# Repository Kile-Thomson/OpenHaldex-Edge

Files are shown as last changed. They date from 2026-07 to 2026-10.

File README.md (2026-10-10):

<p align="center">
  <a href="https://forbes-automotive.com/?utm_source=github&utm_medium=readme&utm_campaign=openhaldex" target="_blank">
    <picture>
      <source media="(prefers-color-scheme: dark)" srcset="/Images/FA-logo-white.png">
      <source media="(prefers-color-scheme: light)" srcset="/Images/FA-logo.png">
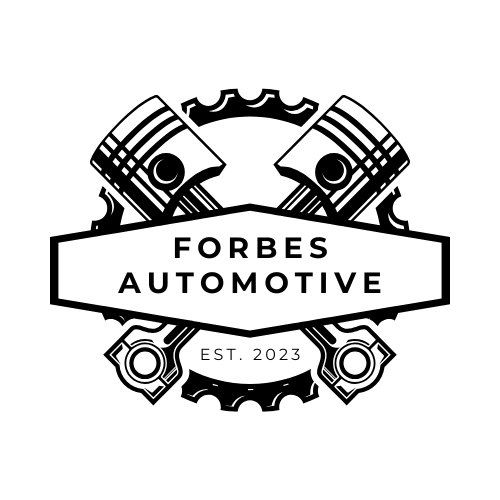
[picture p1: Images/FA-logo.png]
Forbes Automotive
      
    </picture>
  </a>
</p>

# OpenHaldex Edge

> [!IMPORTANT]
> **OpenHaldex Edge is a fork of [Forbes Automotive OpenHaldex-C6](https://github.com/Forbes-Automotive/OpenHaldex-C6).** Forbes did the hard work: the reverse engineering, the Gen2, Gen4 and Gen5 logic, the hardware and the open-source release. Edge starts from their V9.00.6 firmware and adds to it. Same hardware, same wiring, same modes.
>
> Edge uses the **same MIT licence** as upstream, with nothing added to it. There are no plans to restrict it, now or later. Edge's own code is contributed under the same terms. See [Licensing](#licensing).
>
> For assembled modules, official firmware and support, go to [forbes-automotive.com](https://forbes-automotive.com/). Edge is a personal project, not affiliated with or endorsed by Forbes Automotive. Credit for the platform is in [Acknowledgements](#acknowledgements); what Edge adds is in [What Edge adds](#what-edge-adds) and the [CHANGELOG](CHANGELOG.md).

<p align="center">





</p>

OpenHaldex is an open-source **Haldex AWD controller** for Volkswagen and Audi Group vehicles with Haldex Generation 1, 2, 4 (PQ chassis) and 5 (MQB) differentials.

The firmware runs on an **ESP32-C6**. It sits between the car and the Haldex, reads the CAN bus, and changes or generates the Haldex's commands so the differential locks the way you configured. It can work from the car's own CAN signals, or in Standalone mode for conversions with no chassis bus.

Edge takes Forbes's platform and puts day-to-day use first. The whole controller is set up from a phone: a dark web UI served by the module itself, a live engagement gauge and lock trace, a 3D expert map, per-car calibration, backup and restore, and updates straight from GitHub.

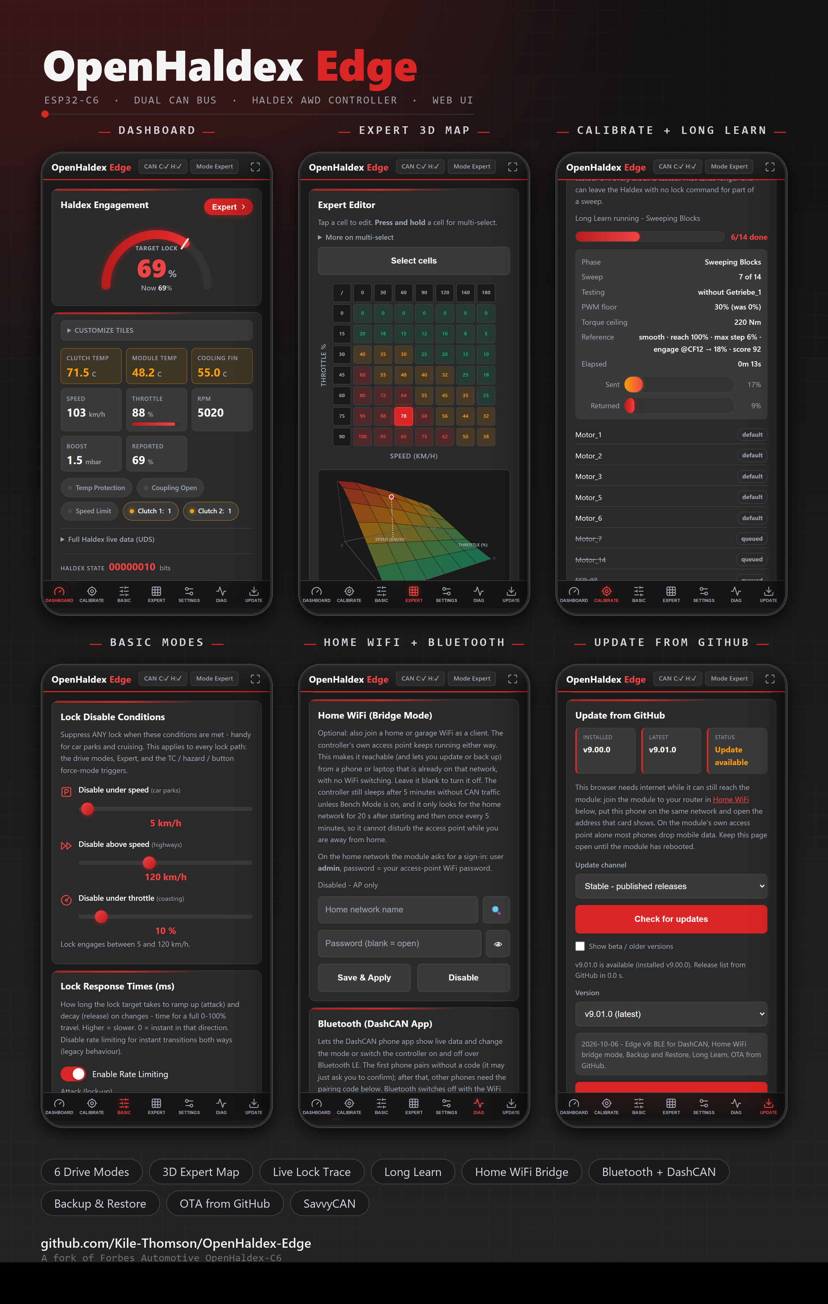
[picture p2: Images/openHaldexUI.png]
OpenHaldex Edge web UI: dashboard, expert 3D map, Long Learn, basic modes, home WiFi and Bluetooth, and update from GitHub


*The Edge web UI, served by the module over its own WiFi access point. No app to install; open a browser on your phone. These screenshots come from the UI running against a simulator, so the numbers are made up and the layout is real.*

## What Edge adds

Everything below runs on the Forbes hardware.

**From Forbes Automotive (V9.00.6, all included):**

- Gen1, Gen2, Gen4 (PQ, GM/SAAB) and Gen5 (MQB 0CQ, 0AY, VAQ) control, Standalone mode, Expert mode with the speed/throttle table.
- Learn Haldex, Long Learn and per-generation CAN frame blocks.
- Live diagnostics: UDS for Gen5, KWP2000 over TP2.0 for Gen2 and Gen4.
- CAN sniffing for SavvyCAN, low power sleep, force modes from TC / hazards / external button.
- Home WiFi (bridge mode), Backup & Restore and Bench Mode, contributed by louij2 (PR #39).
- Bluetooth LE for the DashCAN app, contributed by danati (PR #44).
- Live state and signed commands over ESP-NOW for a can2gauge gauge, and the sleep auto-setup.
- OTA updates with rollback protection, plus the release channels from PR #43.
- The PCB, enclosure and BOM files, now in this repo too.
- The current build toolchain (Arduino 3.3.12 on IDF 5.5.5) and Edge's smaller AsyncTCP task stack.

**Added by Edge:**

- A restyled web UI: dashboard with engagement gauge, live lock trace and connection badge, drive-mode drawer, 3D expert map, tune slots saved on the module, Calibrate tab, installable as a phone app.
- A web-access rule for the home network: a browser reaching the module through your router signs in with the WiFi password. See [Home WiFi](#home-wifi-bridge-mode).
- A forced WiFi password on first power-up, and no CAN injection from the analyzer port until it is set.
- Updating from one file: the release's merged image updates firmware and web UI together.
- Lock engage and release timed in milliseconds, a steering-angle lock taper, per-car geometry for the slip readout, a per-car torque ceiling and a Launch PWM floor.
- Safety work: the learn sweep refuses to run in a moving car, stale CAN inputs fall back to safe values, control state is mutex-guarded, a stalled CAN controller revives itself.
- A host-runnable test suite (`pio test -e native`) and a release build with debug output off.

## Contents

- [Before you flash: upgrading from Edge v8 or upstream](#before-you-flash-upgrading-from-edge-v8-or-upstream)
- [Overview and hardware](#overview-and-hardware)
- [Purchase](#purchase)
- [Supported platforms](#supported-platforms)
- [Modes](#modes)
- [Status LED](#status-led)
- [Basic tab: when lock is allowed](#basic-tab-when-lock-is-allowed)
- [Expert mode](#expert-mode)
- [Calibrate: Learn, lock calibration and geometry](#calibrate-learn-lock-calibration-and-geometry)
- [Long Learn](#long-learn)
- [Frame blocks](#frame-blocks)
- [Changing modes](#changing-modes)
- [CAN broadcast and change-mode request](#can-broadcast-and-change-mode-request)
- [WiFi setup](#wifi-setup)
- [Home WiFi (bridge mode)](#home-wifi-bridge-mode)
- [Backup & Restore](#backup--restore)
- [DashCAN app (Bluetooth)](#dashcan-app-bluetooth)
- [Gauges over WiFi (ESP-NOW)](#gauges-over-wifi-esp-now)
- [Low power mode](#low-power-mode)
- [Bench Mode](#bench-mode)
- [Live diagnostics](#live-diagnostics)
- [CAN sniffing](#can-sniffing-savvycan--gvret)
- [Installation](#installation)
- [Flashing and updating](#flashing-and-updating)
- [Building from source](#building-from-source)
- [PCB and enclosure](#pcb-and-enclosure)
- [Acknowledgements](#acknowledgements)
- [Upstream](#upstream)
- [Licensing](#licensing)
- [Disclaimer](#disclaimer)

---

## Before you flash: upgrading from Edge v8 or upstream

> [!IMPORTANT]
> **The first v9 flash is over USB.** The Bluetooth release changed the flash layout: the firmware slots got bigger (0x1C0000 each) and the web UI partition smaller (0x70000 at 0x390000). A partition table cannot be changed over the air, so a unit on Edge v8, or on an upstream build from before the Bluetooth release, needs one USB flash. After that, updates work over WiFi again. The update page tells you so if you try a file that will not fit.

Things worth knowing when you move from Edge v8:

- **Settings keys are unchanged.** The module still stores everything in the one `openhaldex` settings area, so a flash that leaves that area alone keeps your settings. The merged image is one file covering flash from 0x0 to the end of the web UI partition, and the settings area inside that range is filled with blank flash, so a merged-image USB flash is a factory reset. To keep your settings, flash the separate parts instead, as shown under [First flash over USB](#first-flash-over-usb). Edge v8 has no Backup & Restore, so write down your Expert table or screenshot it either way. v9 units can export a backup (see [Backup & Restore](#backup--restore)).
- **The speed window now gates every lock path.** Disengage under speed, disengage above speed and minimum throttle apply to force modes (TC, hazards, external button) and to Expert mode, not only to the fixed-ratio modes. On Edge v8 those two bypassed the window. If you relied on a force mode locking the car below your "disengage under" speed, lower that setting.
- **From a home network the UI asks for a login.** Over the module's own WiFi nothing changes. See [Home WiFi](#home-wifi-bridge-mode).
- **The learn sweep needs the car stationary** (5 km/h or less). It refuses to start, or aborts, in a moving car.
- **The steering-angle lock taper is on by default on a fresh unit**, with the curve described under [Basic tab](#basic-tab-when-lock-is-allowed). A unit that carries Edge v8 settings keeps whatever its steering setting was.
- **The default correction factor** used before you run a learn stays Edge's (lock + 20)/2, which matches the fit written in the source. Upstream's code currently computes lock/2 + 20; a pull request to line the two up is open upstream. Run the learn and it stops mattering.

---

## Overview and hardware

OpenHaldex sits between the car and the OEM Haldex controller. By default it passes everything through (Stock), and in the other modes it rewrites or generates the Haldex's CAN messages to ask for a different amount of lock. The Gen2, Gen4 (including GM) and Gen5 logic comes from Forbes Automotive; Gen1 comes from A Banging Donk's original project. Gen3 is not supported.

The board is built around an **ESP32-C6 Mini** with WiFi and Bluetooth LE. It has ESD and transient protection and a built-in fuse. Forbes designed it to replace the earlier Teensy 4 (OpenHaldex T4) version, which had no wireless and no on-device setup. On the board:

- Two TWAI (CAN) controllers, one to the car's chassis bus and one to the Haldex.
- An external mode-button input and an on-board RGB LED. See [Status LED](#status-led).
- Brake and handbrake switch inputs, and brake and handbrake outputs for the differentials that need them (brake out on Generation 1 and 2, handbrake out on Generation 1). Some of these outputs need a 10k pulldown resistor on certain platforms (a note from the Forbes hardware docs).

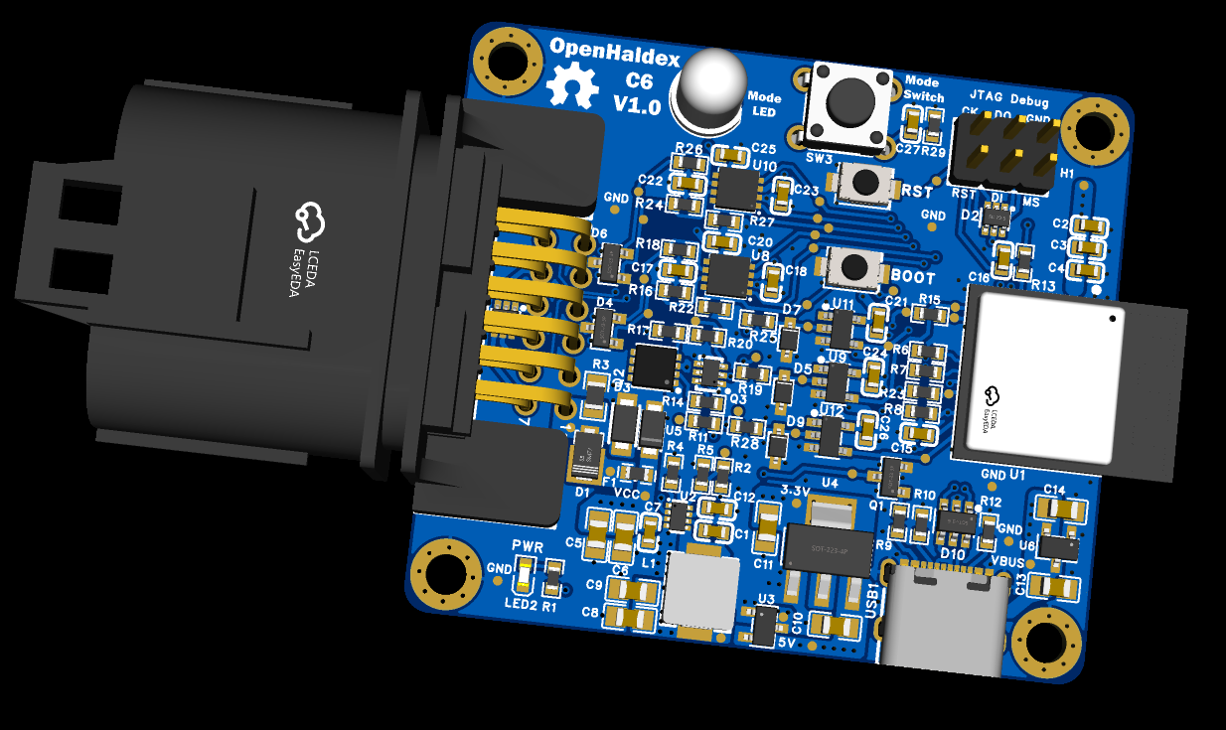
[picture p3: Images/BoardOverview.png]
OpenHaldex-C6 board overview


The pinout is under [Installation](#installation), and the Gerbers and enclosure are under [PCB and enclosure](#pcb-and-enclosure).

---

## Purchase

Assembled modules are sold by Forbes Automotive if you would rather not build one: **[OpenHaldex C6 Controller - Forbes Automotive](https://forbes-automotive.com/products/openhaldex-controller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)**. Edge runs on that hardware.

---

## Supported platforms

- Generation 1 - PQ
- Generation 2 - PQ
- Generation 4 - PQ
- Generation 4 - GM / SAAB
- Generation 4 - Ford (ongoing)
- Generation 5 - MQB (0CQ)
- Generation 5 - MQB (0CQ VAQ)
- Generation 5 - PQ (0AY)

> Gen3 is not supported. The generation list shows a "Generation 3 - Volvo" entry, but there is no Gen3 drive logic behind it.

Pick the generation on the **Calibrate** tab. It has to match the car, or nothing else will behave.

---

## Modes

| Mode | Behaviour | LED colour |
|---|---|---|
| Stock | OEM behaviour (frames pass through untouched) | Red |
| FWD | Zero lock | Green |
| 75:25 | 30% lock | Cyan |
| 60:40 | 40% lock | Neon pink |
| 50:50 | 100% lock | Blue |
| Expert | Lock from your speed/throttle table | White |

The percentages are the lock the controller asks for. In Stock the controller edits nothing: the car's own signals reach the Haldex as they are. In Standalone mode there is no car to pass through from, so Stock holds the clutch open, and the mode button skips Expert.

If you turn on **Disable Controller** (Settings), the module drops to Stock, and mode changes from the web UI and the app are refused until you turn it back on.

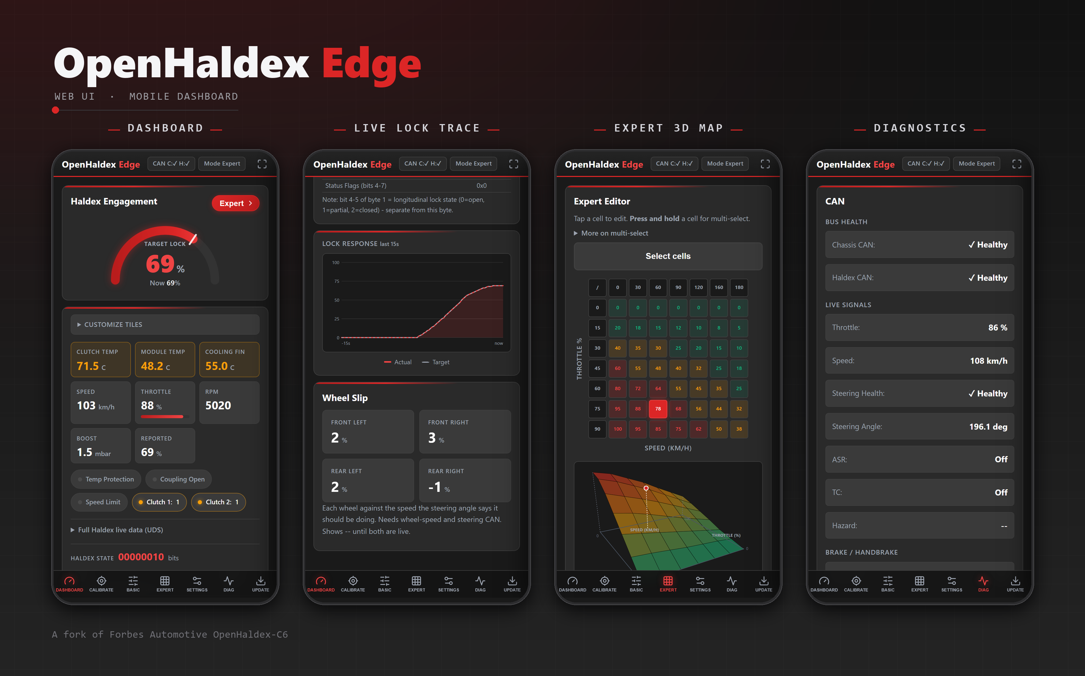
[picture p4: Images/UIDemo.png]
OpenHaldex Edge web UI: dashboard, live lock trace, expert 3D map and diagnostics


*Dashboard with the engagement gauge, the last 15 seconds of target against actual lock, the Expert 3D map and Diagnostics.*

---

## Status LED

The on-board RGB LED shows the current mode, using the colours in the [Modes](#modes) table. Its brightness is a setting (0 to 255, default 255) in Settings or in the DashCAN app. The LED blinks white four times when the WiFi access point restarts. It is off while the module is asleep in [low power mode](#low-power-mode) and comes back on waking.

---

## Basic tab: when lock is allowed

The Basic tab holds three guards that apply to every lock path: the fixed-ratio modes, Expert, and the force modes.

| Setting | What it does | Default |
|---|---|---|
| Disable under speed | No lock below this speed. Car parks, tight manoeuvres. | 0 (off) |
| Disable above speed | No lock above this speed. | 0 (off) |
| Disable under throttle | No lock until the pedal passes this percentage. Coasting. | 0 (off) |

A bound of 0 switches that side off. Lock is allowed only while speed sits inside the window and the pedal is above the threshold.

**Lock response times.** How long the commanded lock takes to ramp, in milliseconds for a full 0 to 100% travel. *Engage* (lock-up) defaults to 0, instant. *Release* defaults to 500 ms. A higher number is slower. The **Enable Rate Limiting** switch turns both ramps off for instant changes either way. The same release ramp is what the DashCAN app's "gradual lock release" setting changes.

**Steering gain taper.** Lowers the lock request as the steering angle grows, so the rear axle is not fighting the front in tight turns and car parks. It works on Gen2, Gen4 and Gen5 (0CQ and VAQ) and applies to every mode that produces lock. The default curve is 100% up to 45 degrees, 80% at 90, 50% at 180 and 20% at 360. In the UI you set where the taper starts, where it is fully applied, and the minimum it drops to. If the steering signal is missing or stale, the taper switches itself off and lock goes back to the full request. The live angle and applied gain are on the Diagnostics tab, so you can check the reading on your car.

---

## Expert mode

Expert mode sets the lock target from **speed and throttle** using a table in the web UI. It needs the car's CAN signals for speed and throttle, so it is not available in Standalone.

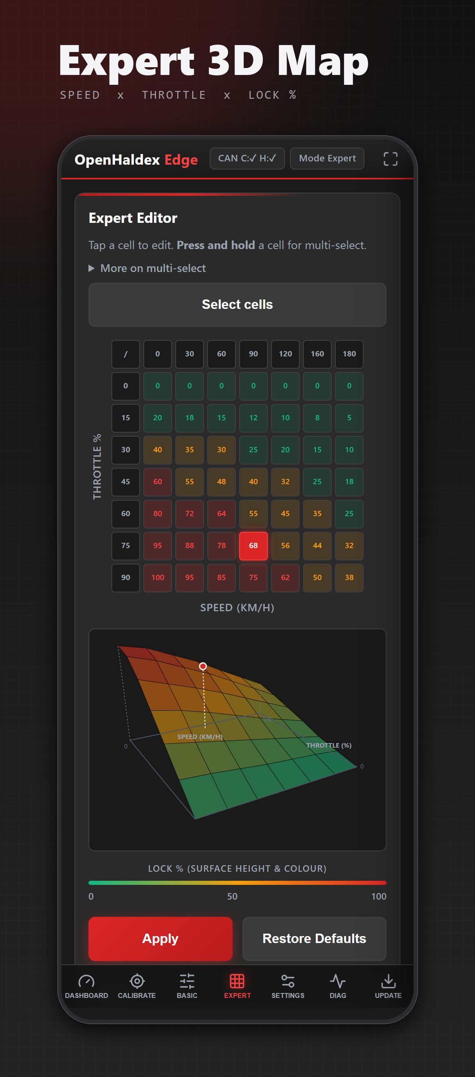
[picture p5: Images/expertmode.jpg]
Expert mode: speed by throttle lock table with the 3D surface below


*Expert mode in the Edge UI: a colour-coded 7 by 7 table over speed and throttle, the live 3D surface below, and a dot that rides the surface as you drive.*

- **Editing.** Tap a cell to edit it. Press and hold to select several cells at once.
- **3D surface.** The same table drawn as a surface: speed and throttle on the floor, lock as height. The operating-point dot shows where you are right now. It is a view; it does not change what is sent.
- **Curve view.** Below the grid, toggle between lock against speed (one line per throttle band) and lock against throttle (one line per speed band).
- **Tune slots.** Five named slots are stored on the module, with save, load and delete. A tune saved from one phone shows on any other phone.
- **Apply / Restore Defaults.** Nothing is written to the Haldex until you apply.

The speed window and the steering taper on the Basic tab apply to Expert too.

---

## Calibrate: Learn, lock calibration and geometry

Set this up once per car, top to bottom. Until a learn table exists, the Dashboard shows a dismissible banner saying lock is running on an estimate, and an uncalibrated guess drives worse than Stock. The tab does not block anything; it only nags.

1. **Generation.** Match the car. See [Supported platforms](#supported-platforms).
2. **Learn Haldex.** The controller steps through every lock percentage and records what your Haldex actually delivers, so a request for 40% gives 40%. Run it with the engine running, the car stationary (5 km/h or less) and Haldex CAN live. It takes a couple of minutes. If you cancel, or the car starts moving, the previous table is put back. Only a finished sweep replaces it. When a table exists the tab plots it: the commanded correction factor against the measured engagement, with a dashed 1:1 reference line. Points above the line mean your Haldex over-responds, below means it under-responds.
3. **Lock calibration** (Gen5). The torque ceiling in Nm, default 220. It lines up the lock you command with the lock the Haldex delivers. Run a Learn, then adjust it until the Sent against Returned line sits on the diagonal. It is not a strength dial: higher does not lock harder, and there is one correct value per car. Leave it alone unless the learn chart shows a gap.
4. **Launch PWM floor** (experimental, default 0%). Raises the minimum clutch PWM the Haldex is told to hold while lock is commanded, so engagement builds faster off the line. It only applies while lock is commanded, and it is kept below the maximum so the Haldex can still modulate. Watch the reported engagement as you tune: if the clutch PWM climbs but engagement was already near 100%, the extra PWM is only heat.
5. **Car geometry** (optional). Wheelbase, front and rear track, steering ratio and the speed below which slip is ignored. The defaults are for an Audi TT Mk3 (2505 mm, 1572 mm, 1543 mm, 15.0:1, 5 km/h). They only feed the per-wheel slip card on the Dashboard. They do not change how lock behaves, so leave them alone unless you want that card to be accurate on another car.

**Gen5 Fix Hunting.** Some Gen5 controllers, specifically the 554K variant, take the torque request in a different packing and can hunt at partial lock. Fix Hunting (default off) switches the Motor_11 packing to the other format. The v9 web UI does not have a switch for it; Long Learn tries it for you on Gen5 when the reference learn is not smooth, and keeps it only if the result is better.

---

## Long Learn

If a normal learn is not clean (jumps, plateaus, never reaches 100%), Long Learn finds out which [frame blocks](#frame-blocks) the Haldex really needs. It is on the Calibrate tab. Run it with the car stationary, the engine running and Haldex CAN live. Allow 6 to 8 minutes on Gen5.

The lock-driven blocks (the ones that carry the lock request, marked *core*) are always sent unless you switch on *Also test the lock-driven (core) blocks*, which tests them too. Every other block is a candidate. The phases:

1. **Reference.** Every block is switched on, as Standalone sends them, and one full 0 to 100% learn runs on your current settings.
2. **BPK Adjust** (Gen5 0CQ and VAQ only, and only if the reference hunts or does not reach about 90%). It tries Fix Hunting and keeps it only if the sweep improves. If lock is still short it raises the torque ceiling in 40 Nm steps, up to 500 Nm, until the target is reached. Whatever wins is kept when the run completes.
3. **Prove it.** The all-on sweep on the settled settings must be a smooth 100%. Then two quick reads at 20, 40, 70 and 100% lock with everything on; how far the two reads differ is the noise level that blocks are judged against. If the sweep is not smooth, or the reads differ by more than 10%, the run stops and says why. There is nothing trustworthy to compare blocks with.
4. **Testing blocks.** Each candidate is switched off on its own, with everything else on, read at the same four points after a release to 0, then switched back on. A block that changes the reading by more than the noise is *needed* (or *affects, higher without* if the reading went up, which keeps it on but flags it). One that makes no difference is *no effect*. Each verdict shows how far the reading moved. Tick *Also test the lock-driven (core) blocks* to test those too; that takes longer and can leave the Haldex with no lock command for part of a run.
5. **Confirmation.** Every *no effect* block is switched off together and a full sweep is compared point by point with the reference. If it still matches, that set and its table are stored. If not (a step between the test points, or two frames covering for each other) every block is left on, the reference table is stored and the run is marked as an interaction.

The tracker shows the phase, the sweep count, the block under test, the current floor, torque ceiling and Fix Hunting state, the reference score with its noise level, and live Sent and Returned bars. Cancelling, or a run that stops, puts back the blocks, floor, torque ceiling, Fix Hunting setting and learn table you had before. Moving above 5 km/h aborts the run the same way.

A **chassis notes** box (saved on the module, up to 200 characters) and **Export report (.txt)** produce a plain text record of the car, the calibration values, the recommended block set, the sweep log and the stored table. It is useful for sharing a known good layout for a chassis.

---

## Frame blocks

On the Calibrate tab, the **Frame blocks** list shows each CAN frame OpenHaldex can edit for your generation, with a switch for each. Switched off, the car's own message passes through untouched. Switched on, OpenHaldex modifies or generates that frame. Changes apply immediately and are saved per generation, and **Reset to Defaults** restores the generation's standard set.

You would use this to find which edited frame upsets a learn or raises a fault code, to tailor a car that behaves unusually, or to add and remove signals while developing a new feature. Most users never need to touch it; Long Learn does the same job automatically. It applies in both normal and Standalone mode, and only to the generation currently selected.

---

## Changing modes

**On-board button.** A short press cycles Stock, FWD, 50:50, 60:40, 75:25, Expert, then back to Stock. In Standalone mode Expert is skipped. A long press clears the WiFi password and restores the default network name, then the access point restarts in first-run setup mode. See [WiFi setup](#wifi-setup).

**External button.** A short press cycles modes the same way. If you set **External button** to "Hold: Force Mode" in Settings, a short press does nothing and a long press engages the force mode you chose for it.

**WiFi.** The web UI at `192.168.1.1` or `openhaldex.local`.

**CAN.** Send a mode number to `0x6A0`. See [CAN broadcast and change-mode request](#can-broadcast-and-change-mode-request) below.

**Force modes from the car's own signals.** Each of these is optional, off by default, and set up in Settings. Each has its own target mode (default 50:50). A priority setting decides which one wins when more than one is active.

- **TC / ESP button.** Pressing the traction control button to switch ESP off triggers force mode. The module reads the ESP-disabled bit (byte 7 on PQ, byte 6 on MQB).
- **Hazard switch.** While the hazards flash, the force target applies. Read from Blinkmodi_02 (`0x366`) on MQB. Pick FWD as the target and you get a way to open the coupling for towing, recovery or limping home.
- **External button.** The hold behaviour above.

---

## CAN broadcast and change-mode request

One setting, **Broadcast over CAN** (Settings, on by default on a fresh unit), switches on both of these:

- the module reads mode-change requests on `0x6A0`;
- the module sends its state on `0x6B0`.

> [!NOTE]
> Turning this on puts two CAN IDs on your bus. Check nothing else on the car already uses them.

### Change-mode request

Send a standard 11-bit frame to `0x6A0` with the mode number in byte 0 (`data[0]`). If you send 8 bytes, set the unused ones to `0x00`. With Broadcast over CAN off the module ignores the frame, and a value above 5 is ignored too.

| CAN ID | Byte 0 | Mode |
|---|---|---|
| `0x6A0` | `0x00` | Stock |
| `0x6A0` | `0x01` | FWD |
| `0x6A0` | `0x02` | 50:50 |
| `0x6A0` | `0x03` | 60:40 |
| `0x6A0` | `0x04` | 75:25 |
| `0x6A0` | `0x05` | Expert |

The request is read from the chassis bus.

### Broadcast state

The module sends this on `0x6B0` every cycle, as 8 data bytes. Aftermarket ECUs or displays can use it to show the Haldex state.

```
data[0] = reserved (always 0)
data[1] = 1 when Standalone mode is on, otherwise 0
data[2] = engagement raw byte returned by the Haldex
data[3] = lock target percent requested by the firmware (0-100)
data[4] = vehicle speed in km/h, clamped at 255
data[5] = mode override flag
data[6] = current mode number (0-5, same numbers as the request table)
data[7] = pedal value (0-100%)
```

---

## WiFi setup

1. Join the access point **OpenHaldex-C6** (you can rename it).
2. Open `192.168.1.1` or `openhaldex.local` in a browser.

### First power-up: set a password

A fresh or factory-reset module has no password. The access point comes up open, but only so you can reach one page: the browser is sent to `/setup`, which asks for a WiFi password and confirmation. Nothing else on the module answers until you set it, and CAN injection from the analyzer port is refused. Once you submit, the access point restarts protected with that password and the setup page closes. The password is the **WPA2 password of the access point** and also the sign-in for the [home-network side](#home-wifi-bridge-mode). It must be 8 to 64 characters.

There is no default password and nothing to build or flash to set one.

**Changing it later.** The WiFi Access Point card on the Diagnostics tab changes the network name and password. The access point always needs a password, so there is no "open" option there.

**Forgotten it?** Long-press the mode button on the unit. That clears the password and restores the default network name, and the setup page asks for a new one. Anyone with physical access to the module can do this, which is the intent: the unit is in your hands.

### Connecting from a phone

Use your phone's normal WiFi settings, not its Personal Hotspot. The module is the access point: it broadcasts its own network like a router does, and your phone joins it.

The module has no internet connection and does not need one. Your phone will say the network has no internet. That is expected; dismiss it. If your phone keeps dropping the network because of that warning, choose "Stay connected". The module answers the phone's internet check with a bare 404 (so no sign-in page opens) and hands out no gateway or DNS, so the phone keeps using mobile data for everything else. That includes the [GitHub update check](#updating-over-wifi), which normally works straight from the module's own WiFi.

Do not use your phone's Personal Hotspot for this. A hotspot shares your phone's data with other devices, which is not what is needed here. If you get stuck, forget the network on the phone and join again; the module runs the same whether or not anything is connected.

---

## Home WiFi (bridge mode)

Optional. The module can also join a home or garage WiFi network as a client while keeping its own access point running. Then it is reachable at `openhaldex.local`, or at the address the card shows, from any phone or laptop already on that network, without switching WiFi to the module. It is also the way to update or back up from a laptop at home, and the fallback for a phone that drops mobile data on the module's own WiFi. Leave the field blank and nothing changes.

Set it up on the **Diagnostics** tab under **Home WiFi (Bridge Mode)**: pick the network from the scan (or type a hidden one), enter its password, press **Save & Apply**. The card then shows the connection state, the address and the signal strength. The same card is repeated on the **Update** tab, because this is the fallback when the GitHub update check cannot get internet from the module's own WiFi. Endpoints: `GET/POST /api/wifi/sta` with `{ssid, password}` (an empty `ssid` turns it off), `POST /api/wifi/sta/reset` and `GET /api/wifi/scan` (asynchronous; poll until `scanning` is false).

> [!IMPORTANT]
> Putting the module on your home network means other devices on that network can reach it. So a browser coming in through the home network has to sign in: user name `admin`, password your access point's WiFi password. The check covers every page and every `/api` and `/ota` request. A phone joined directly to the module's own access point does not sign in; joining that network already needed the password. The CAN analyzer's host-to-CAN injection is also refused for home-network clients.

Things to know:

- **One radio.** The ESP32-C6 shares one radio between its access point and the home connection. A scan or connection attempt pulls it off the access point's channel for a second or two. So the module only looks for your home network for 20 seconds after starting, then once every 5 minutes. A saved network cannot keep interrupting the access point while the car is away from home.
- **Sleep.** Bridge mode mostly does not change [low power mode](#low-power-mode). With no CAN traffic and nobody using the UI, the module still sleeps after five minutes and drops off the home network. A browser that has the UI open through your router counts as a user, so an update over the bridge is not cut off.
- **Open networks.** A blank home-network password connects to an open network. The module accepts it; think before you do.
- **The backup tool.** `tools/openhaldex_config.py` does not send a login. Use it while joined to the module's own WiFi.

---

## Backup & Restore

A USB flash can wipe the settings, and nobody wants to re-type an Expert table. **Diagnostics > Backup & Restore** exports the Expert tune, saved map slots, the frame-block choices, every setting and the WiFi names to a JSON file, and imports them back in one go.

WiFi passwords are write-only on the device. They are never written to the file, and after an import you are asked once for any that were set. The Bluetooth pairing code is also left out of the file.

The same file works from a computer with [`tools/openhaldex_config.py`](tools/openhaldex_config.py):

```
python tools/openhaldex_config.py export backup.json
python tools/openhaldex_config.py import backup.json
python tools/openhaldex_config.py import backup.json --tune-only
python tools/openhaldex_config.py --host openhaldex.local export backup.json
```

The default address is `192.168.1.1`. The tool needs to be on the module's WiFi (see the note under [Home WiFi](#home-wifi-bridge-mode)). A backup made with Bench Mode on is imported without switching Bench Mode on while CAN is live. Export before you re-flash. Backup & Restore and Bench Mode were contributed upstream by louij2 (PR #39).

---

## DashCAN app (Bluetooth)

The module talks Bluetooth LE to the **DashCAN** phone app, so the basics are on the phone without joining the module's WiFi. The web UI stays the place for everything else (Expert map, learning, generation, frame blocks, updates). Bluetooth was contributed upstream by danati (PR #44).

**From the app:**

- **Live.** Mode buttons, controller on/off, lock target and actual, speed, throttle, rpm, boost, steering angle, CAN health and Haldex warnings.
- **Settings.** The ones you change per situation: force modes, brake and handbrake release, the speed and throttle window, steering-angle scaling, gradual lock release and its rate, live diagnostics and LED brightness. A change on the web UI shows in the app and the other way round.
- **Haldex diagnostics.** Temperatures, supply voltage, clutch current and duty (and oil pressure and estimated torque on Gen4). Needs [Live diagnostics](#live-diagnostics) switched on.
- **Gauges.** AWD Lock, AWD Lock Target, Steering and the Haldex temperatures for the app's dashboards and drive recordings.

**Connecting.** Bluetooth is on by default. The module appears as `OpenHaldex-XXXX` (the last two bytes of its address) and the app connects to the first one in range, or you pick it on the app's Bluetooth screen. Live data needs no pairing. The first change from a phone pairs it:

- The **first phone** pairs without a code (it may just ask you to confirm).
- After that, **every new phone needs a 6-digit pairing code**, shown on an already paired phone and in the web UI.

**On the module.** The Bluetooth card on the Diagnostics tab has the enable switch, a phone-connected indicator, the pairing code and **Forget Paired Phones**. Forgetting removes every paired phone, makes a new code, and lets the next phone pair without one (also forget the device in the phone's own Bluetooth settings). Bluetooth sleeps with the WiFi in [low power mode](#low-power-mode).

> [!NOTE]
> Until the first phone has paired, on a new module or right after Forget Paired Phones, anyone in Bluetooth range could be that first phone. Pair yours straight away. Firmware is never updated over Bluetooth.

The protocol is written up in [`documents/MOBILE_APP_OPENHALDEX.md`](documents/MOBILE_APP_OPENHALDEX.md), so other apps can use it.

---

## Gauges over WiFi (ESP-NOW)

The module broadcasts its live state over ESP-NOW, a short-range WiFi link that needs no router, so a Forbes **can2gauge** CAN gauge can show the Haldex with power only and no CAN connection. About ten times a second it sends the mode, generation, lock target and actual, speed, rpm, throttle, per-wheel slip, the Long Learn progress and the live diagnostics values. This was added upstream by Forbes Automotive.

With control allowed, a gauge can also change the drive mode, change the generation, start, cancel or clear a Learn, start or cancel Long Learn, and switch the controller on and off. Generation and learn commands are only accepted with the car stopped (or no chassis CAN at all). Every command is signed with the **WiFi password** and carries a one-use number from the module, so a gauge only works if it knows the same password, and a captured command cannot be replayed. The password is not sent. With analyzer mode on, commands are refused.

Both switches are on the Diagnostics tab, in the *Gauges over WiFi (ESP-NOW)* card, and both default to on:

- **Send status to gauges.** Off stops the broadcast and the link.
- **Allow gauges to change settings.** Off keeps the broadcast but refuses every command.

ESP-NOW follows the WiFi access point: it starts when the access point is up and stops before the WiFi goes to sleep, so a gauge goes quiet while the car is parked in [low power mode](#low-power-mode). The settings are part of Backup & Restore.

---

## Low power mode

The module is made to live on a **permanent +12 V** feed. Upstream quotes about 14 mA asleep (car off, WiFi off, CAN quiet) and about 50 mA awake. Those figures are Forbes's and have not been measured on Edge builds. Edge differs in one way that matters: it does not use automatic CPU light sleep (see Layer 2), so it probably draws more than that asleep. Treat the numbers as a guide.

There are three layers, each building on the one before. All are set on the Settings tab.

### Layer 1: idle AP shutdown (on with CAN Sleep, which is on by default)

After **5 minutes** with no WiFi clients, no one with the UI open, and the chassis bus below the wake threshold, the module shuts down the WiFi access point, Bluetooth, the ESP-NOW gauge link and the LED. Turning **CAN Sleep** off keeps them up permanently. When the frame rate rises above the threshold again (car unlocked or started), WiFi comes back on its own.

### Layer 2: CAN Sleep (on by default)

The **CAN Sleep** switch turns the sleep logic on. With it on, the CPU clock scales between 40 and 160 MHz, following load. The CAN transceivers stay powered and listening, so the first frame above the threshold wakes the module.

Edge keeps the CPU running while the module is "asleep". Upstream lets the CPU light-sleep, but on the C6 the CAN controller can power down in light sleep and come back stopped, with nothing to wake it, which leaves a dead module until a replug. Edge turns automatic light sleep off, so the CAN receive task, the frame counter and the wake check always keep running, and a stopped CAN controller is restarted on its own.

The clock limits are set at boot, so toggling CAN Sleep takes full effect after a restart. This layer is the recommended starting point.

### Layer 3: CAN Sleep (Aggressive) (off by default, builds on Layer 2)

**CAN Sleep (Aggressive)** keeps everything above and also:

- puts the CAN transceivers in standby;
- drops the CPU minimum clock to 10 MHz;
- trims the WiFi transmit power;
- wakes by interrupt: each CAN receive line triggers on the first bus edge and brings the transceivers back within microseconds.

Use it when the car sits unused for days and you want the lowest standby current.

### How to set it up

Every car idles its CAN bus at a different rate, so the **LP Wake Threshold** (default 1100 frames per second) has to sit just above your car's parked rate. While the chassis bus is at or above the threshold the module stays awake; below it, it sleeps.

**Gen5: automatic.** Selecting a Gen5 generation asks *Enable CAN sleep and set it up automatically?* (and asks again whenever you switch back to Gen5). Say yes, then just use the car. The next time it is left with no phone connected, the module:

1. switches on CAN Sleep and CAN Sleep (Aggressive);
2. waits until the car is parked: speed 0, engine off and ignition off (`ZAS_Kl_15` in Klemmen_Status_01, `0x3C0`), with real CAN seen since power-up;
3. averages the chassis frame rate for **15 minutes**, restarting the count if a phone connects, the ignition comes on or the car moves;
4. sets the LP Wake Threshold to that average plus 300 frames per second (rounded up to 10) and saves it.

It runs once. Sleep stays off until it has finished, so the module never sleeps on a wrong threshold. The Controller Options card shows *armed* or the measured average; tick the switch again to repeat it.

**Manual (any generation).**

1. Park and lock the car. Wait 15 minutes, or until the chassis bus goes quiet.
2. Stay joined to the module's WiFi, which keeps it awake. On the Settings tab watch the **Chassis fps** and **Haldex fps** counters and note the highest reading while the car sleeps. Some cars go fully quiet; others keep a gateway heartbeat of several hundred frames per second.
3. Set the **LP Wake Threshold** a few hundred above that reading, for example 1100 for a car parked at 800.
4. Make sure **CAN Sleep** (and optionally **CAN Sleep (Aggressive)**) is on, then disconnect from the WiFi.

The module now sleeps and wakes when the frame rate rises above the threshold.

> [!NOTE]
> **Standalone mode:** with no chassis bus the slider does not apply. The module wakes on a fixed 50 frames per second of Haldex-bus traffic.

> [!NOTE]
> **Switched-ignition installs:** if the module is already powered off with the ignition, low power mode saves little and is optional.

A computer on the module's USB port keeps the WiFi up, so you can use the dashboard on the bench without a CAN source.

---

## Bench Mode

The module cannot tell a harnessed car that is asleep from no harness at all: both look like zero CAN traffic. So on the bench with CAN Sleep on, the WiFi drops after five minutes. **Bench Mode** (Settings, under CAN Sleep) holds the WiFi up regardless.

It clears itself. The moment either CAN bus shows traffic, Bench Mode switches itself off and saves that, and normal sleep resumes, so it cannot weaken the battery protection once the unit is in the car. The UI also greys the switch out while CAN is detected, and the module ignores an attempt to turn it on while CAN is live.

---

## Live diagnostics

OpenHaldex can ask the Haldex for live measurements and show them in the web UI, as a scan tool would. This uses the module's diagnostic channel, so it is **off by default** (Settings > **Enable Live Diagnostics**). It picks the protocol from the generation you set.

- **Gen5 (0CQ, 0AY, VAQ): UDS** over ISO-TP. Terminal voltage, control module temperature, clutch temperature, cooling fin temperature, clutch current, PWM and voltage. Clutch and fin temperatures show `--` when the decoded value is not plausible. Forbes report the scaling was checked against VCDS on a heat-soaked bench module across the full temperature range.
- **Gen2 and Gen4: KWP2000 over VW TP2.0.** The module opens a TP2.0 channel, starts a diagnostic session and reads the measuring blocks. Oil temperature, clutch plate temperature, supply voltage, oil pressure, estimated torque, clutch valve duty and current. Gen4 values are decoded and, per Forbes, confirmed against VCDS; the raw measuring-block bytes are also exposed so other values can be worked out.

With Live Diagnostics on, the Dashboard's standard Haldex data card is replaced by the UDS card on Gen5 or the TP2.0 card on Gen2 and Gen4.

If VCDS, ODIS or another scan tool is connected, the module detects its requests on the bus and pauses its own polling until the tool goes quiet, so the two do not collide. If a tool still will not connect, switch Live Diagnostics off. Extra CAN traffic can cause spurious dash errors.

**Diagnostic tester reads.** Separately from the polling above, OpenHaldex answers three supplier-specific data identifiers on the Haldex address, so a tester on the OBD port (such as the Rokketek gauge) can use them: the lock command and engagement (`0xFDA0`), per-corner wheel slip (`0xFDA1`), and a write to set the drive mode (`0xFDA2`). The slip values are each wheel's speed against what the steering geometry predicts, so a straight launch and a mid-corner break-loose both read as real slip. The four slip values are also on the Dashboard.

---

## CAN sniffing (SavvyCAN / GVRET)

Switch on **Analyzer Mode** in Settings to capture CAN frames from both buses.

> [!WARNING]
> Analyzer Mode turns off active Haldex control and puts the module back to OEM pass-through. It also stops the `0x6B0` broadcast.

The analyzer speaks GVRET to SavvyCAN, over WiFi (TCP port 23) or over the USB serial port. Choose with the **SavvyCAN via WiFi** and **SavvyCAN via Serial** switches.

1. Join the module's WiFi and enable SavvyCAN via WiFi in Settings.
2. In SavvyCAN: Connection > Add New Device Connection > Network Connection (GVRET).
3. IP `192.168.1.1`, port `23`, CAN speed `500000`.

For USB, connect the module with a USB-C cable, enable SavvyCAN via Serial in Settings, then in SavvyCAN add a new device connection, Serial Connection (GVRET), pick the module's COM port and set the speed to 500000. No WiFi is needed.

The SavvyCAN feature comes from Chris (meatro)'s OpenHaldex-S3. It is the easy way to see what the car says on its bus when you want to add a feature.

Receiving is always allowed. **Host-to-CAN injection** (sending frames from SavvyCAN onto the car's bus) is refused until the access point password is set, and always refused for a client that came in through the home network.

---

## Installation

> [!TIP]
> ### Optional Plug & Play Harness (Recommended)
>
> Recommended for quick installation (and removal)  -  typically **<10 minutes** on Generation 1 Controllers.
> The latest harnesses for Generation 5 are even simpler and you'll be experiencing your Haldex controller in less than 30 seconds:

- Lift the rear seat
- Split the factory 6-pin Haldex connector
- Install your new harness & OpenHaldexC6 Controller
- Drive it (you could put the seat back down too, if you want!)

> For Generation 1 Controllers:

- Remove original connector and install the long end of the harness onto the differential.
- Route the long end along with the original connector back into the boot floor via. the OEM grommet
- Install and secure the OpenHaldexC6 Controller to the new harness, pairing it with the original plug

Forbes's step-by-step instructions are in the **[OpenHaldex Installation Guide](https://openhaldex.com/docs/OpenHaldex_Installation_Guide.pdf)**. This section is carried over from the Forbes README.

Video: **Installation demo (YouTube Short):** https://youtube.com/shorts/iUkNh9NbyKY?si=IhgqLIi0WM8wXqe9

Video: **Installation demo (YouTube Short):** https://youtu.be/Wu-u-Dz1444

> [!WARNING]
> ### Manual Wiring (No Harness)
>
> Modules sold without a harness include connector pins for manual wiring. This is a little harder and more involved than using the optional harness, but following the installation guide above it can still be completed easily. 

Gen1:
- Chassis Connector: `1J0-973-714`
- Haldex Connector: `1J0-973-814`

Gen4:
- Haldex Connector  -  `VW 1J0-973-713`
- Vehicle Connector  -  `VW 1J0-973-813`

Build this as a **Y-branch** harness between the two VW 8 or 6-pin connectors, with a long tail to the MX plug.

Routing summary:

- **Permanent power (Term30) and ground must also be branched to the OpenHaldex controller**:
  - Term30 -> MX Pin 1
  - Ground -> MX Pin 2
  
- Chassis CAN is taken from the Vehicle side and sent to the controller:
  - Vehicle Pin 5 -> MX Pin 3 (Chassis CAN Low)
  - Vehicle Pin 6 -> MX Pin 4 (Chassis CAN High)

- Returned CAN from the controller then goes to the Haldex side:
  - MX Pin 5 -> Haldex Pin 5 (Haldex CAN Low)
  - MX Pin 6 -> Haldex Pin 6 (Haldex CAN High)

Generation 1 to 4:
- Vehicle Connector  -  `VW 1J0-973-714`:

| Pin | Signal | Notes |
|----|---|---|
| 1 | Term15 | Pass-through: Vehicle -> Haldex |
| 2 | Ground | Pass-through: Vehicle -> Haldex and branch to MX Pin 2 |
| 3 | Brake Light | Pass-through: Vehicle -> Haldex |
| 4 | Handbrake | Pass-through: Vehicle -> Haldex |
| 5 | K-Line | Pass-through: Vehicle -> Haldex |
| 6 | N/A | Not Used |
| 7 | Chassis Low | To MX Pin 3 (chassis side) |
| 8 | Chassis High | To MX Pin 4 (chassis side) |

- Haldex Connector  -  `VW 1J0-973-814`:

| Pin | Signal | Notes |
|----|---|---|
| 1 | Term15 | Pass-through: Vehicle -> Haldex |
| 2 | Ground | Pass-through: Vehicle -> Haldex and branch to MX Pin 2 |
| 3 | Brake Light | Pass-through: Vehicle -> Haldex |
| 4 | Handbrake | Pass-through: Vehicle -> Haldex |
| 5 | K-Line | Pass-through: Vehicle -> Haldex |
| 6 | N/A | Not Used |
| 7 | Chassis Low | To MX Pin 5 (Haldex side) |
| 8 | Chassis High | To MX Pin 6 (Haldex side) |

Generation 5:
- Vehicle Connector  -  `VW 1J0-973-813`:

| Pin | Signal | Notes |
|----|---|---|
| 1 | Term15 | Pass-through: Vehicle -> Haldex |
| 2 | Ground | Pass-through: Vehicle -> Haldex and branch to MX Pin 2 |
| 3 | Term30 | Pass-through: Vehicle -> Haldex and branch to MX Pin 1 |
| 4 | N/A | Not used |
| 5 | Chassis Low | To MX Pin 3 (chassis side) |
| 6 | Chassis High | To MX Pin 4 (chassis side) |

- Haldex Connector  -  `VW 1J0-973-713`:

| Pin | Signal | Notes |
|----|---|---|
| 1 | Term15 | Pass-through: Vehicle -> Haldex |
| 2 | Ground/MALT | Pass-through from Vehicle side |
| 3 | Term30 | Pass-through from Vehicle side |
| 4 | N/A | Not used |
| 5 | Haldex Low | From MX Pin 5 (Haldex side) |
| 6 | Haldex High | From MX Pin 6 (Haldex side) |

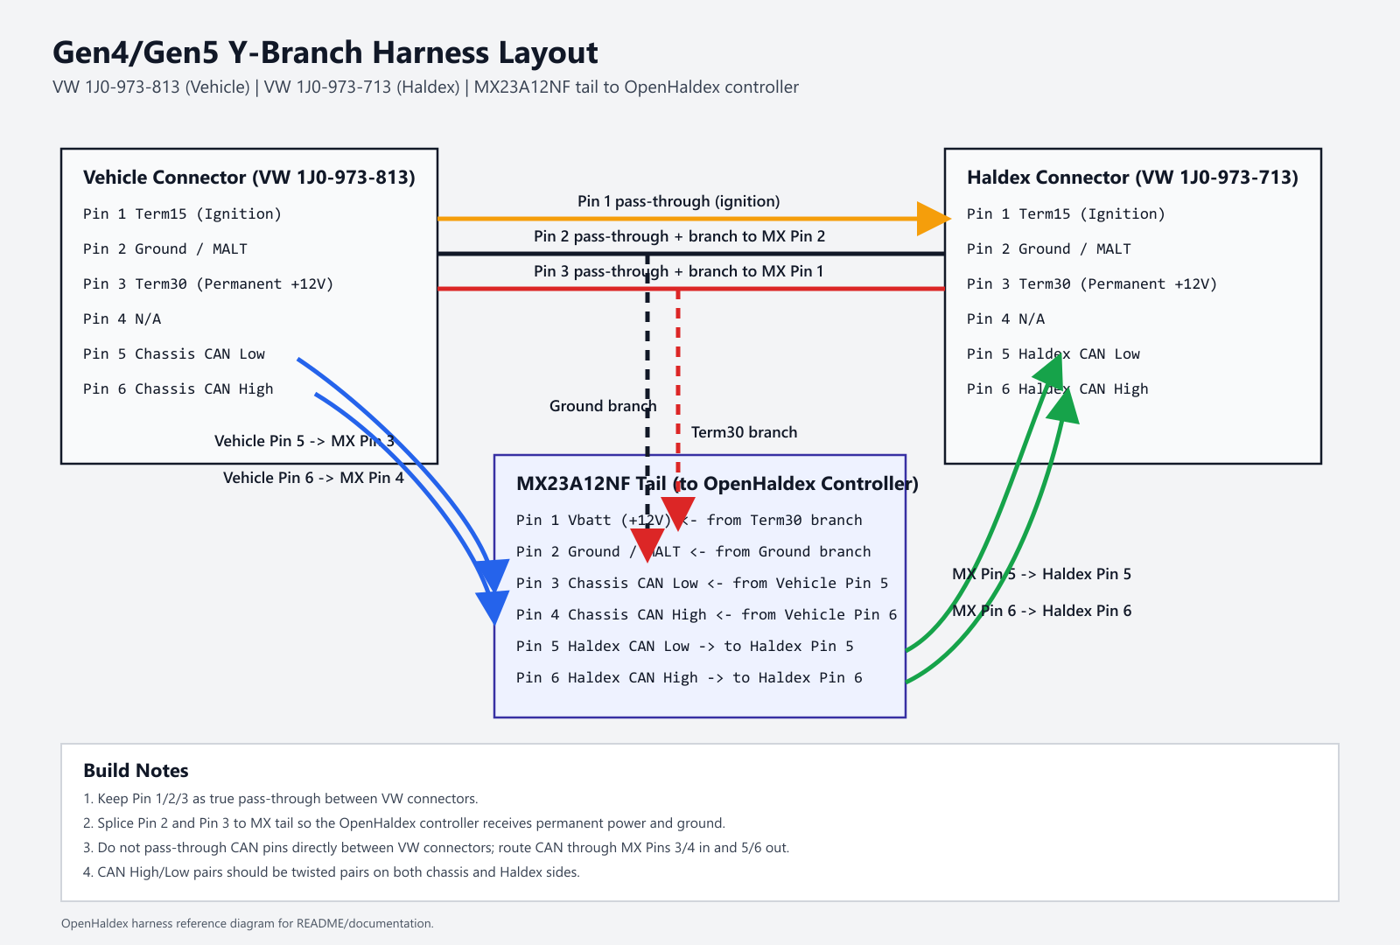
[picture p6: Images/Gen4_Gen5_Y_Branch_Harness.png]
Gen4/Gen5 Y-Branch Harness Diagram


### MX23A12NF Connector Pinout

| Pin | Signal | Notes |
|----|---|---|
| 1 | Vbatt | +12 V |
| 2 | Ground/MALT | Ground |
| 3 | Chassis CAN Low | To chassis/ECU side |
| 4 | Chassis CAN High | To chassis/ECU side |
| 5 | Haldex CAN Low | To Haldex differential |
| 6 | Haldex CAN High | To Haldex differential |
| 7 | Switch Mode External | +12 V to activate |
| 8 | Brake Switch In | +12 V input |
| 9 | Brake Switch Out | Gen1 / 2 differentials only |
|10 | Handbrake Switch In | +12 V input |
|11 | Handbrake Switch Out | Gen1 differentials only |

---

## Flashing and updating

### First flash over USB

Connect the module with a **data-capable USB-C cable**; power-only cables will not work.

Each tagged [release](https://github.com/Kile-Thomson/OpenHaldex-Edge/releases) attaches one merged image, `openhaldex-c6-<tag>-merged.bin`. It holds the bootloader, partition table, firmware and web UI, so it is a complete flash-from-scratch build. Flash it at offset `0x0`:

```sh
esptool.py --chip esp32c6 write_flash 0x0 openhaldex-c6-<tag>-merged.bin
```

Or drag it into a browser flasher such as [ESP Web Tools](https://web.esptool.js.org/): connect the module, press Connect, pick its serial port, then flash the file at offset 0. Do not use Forbes's Module Software Updater page for Edge. It flashes their firmware, not this one. `SHA256SUMS.txt` is attached so you can check the download. The release also carries the separate app, littlefs, bootloader and partition binaries.

The merged image blanks the settings area, so flashing it resets the module's settings.

**Keeping your settings (Edge v8 to v9).** The settings area sits at the same place (`0x9000`) on v8 and v9, and v9 reads v8's settings unchanged. To keep them, flash the separate parts instead of the merged image, and clear the boot selector so the module starts the new firmware:

```sh
esptool.py --chip esp32c6 erase_region 0xd000 0x2000
esptool.py --chip esp32c6 write_flash \
  0x0      bootloader.bin \
  0x8000   partitions.bin \
  0x10000  openhaldex-c6-<tag>-app.bin \
  0x390000 openhaldex-c6-<tag>-littlefs.bin
```

The offsets come from the v9 partition table; the release's `manifest.json` on the `ota` branch lists the same ones. Write down your Expert table anyway, in case something goes wrong. Once you are on v9, export a backup before any USB flash.

### Updating over WiFi

Once a module is on the v9 flash layout, update it from its **Update** tab. Nothing on the module fetches from the internet itself: your browser gets the files and pushes them to the module.

**Update from GitHub.** The browser needs internet while it can still reach the module. On the module's own WiFi the phone normally keeps mobile data (see [Connecting from a phone](#connecting-from-a-phone)), so the check works as it is. If your phone drops mobile data there anyway, or you are on a laptop at home, use [Home WiFi](#home-wifi-bridge-mode): join the module to your router, put the device on the same network, and open the address the Home WiFi card shows.

1. Press **Check for updates**. The page contacts the module first, then fetches the release list from this repository's `ota` branch on GitHub, with a mirror as a fallback. If there is no internet it reads the module's bridge status and tells you what to do: join the network the module is on, fix a dropped link, or set up Home WiFi.
2. Pick a version. Newer stable releases are listed; tick **Show beta / older versions** for the rest. The **Latest build** channel also offers the newest release again, for when its files were rebuilt in place after a fix landed. Going backwards is allowed, and the confirm warns that an older release may not have this page.
3. Press **Install**. The page shows six stages (get UI, flash UI, verify, get firmware, flash firmware, reboot) with elapsed time. The web UI goes first, then the firmware, and the page waits for the reboot.

Keep the page open and the screen on during an install.

**Update from a File.** A card on the same tab takes a file you already downloaded, with no internet needed. Give it the release's merged image (it updates firmware and web UI together) or a bare `firmware.bin` or `littlefs.bin`; it works out which from the file's first bytes. A merged image is split by flash offset, and the bootloader, partition table and settings are never touched.

**From the command line.** The module takes an HTTP upload to `/ota/update` (merged image, firmware or web UI image) or `/ota/update/fs` (web UI image only). It does not speak espota, so PlatformIO's `--upload-port <ip>` will not work.

```sh
curl -F "update=@firmware-merged.bin" http://192.168.1.1/ota/update
curl -F "filesystem=@littlefs.bin" http://192.168.1.1/ota/update/fs
```

Through the home network add `-u admin:<your WiFi password>`. `GET /ota/check` reports whether an update is allowed right now and why not.

**Safety gate.** In the bench (no CAN detected) updates are allowed any time. In the car, an update needs the car stationary, both CAN buses healthy and no Haldex temperature fault; the module drops to Stock when an update starts. A new firmware image boots in a pending state and is confirmed only after the web UI has been reached on it or after 60 seconds of uptime. If it crash-loops before then, the bootloader goes back to the previous firmware. A web UI update unmounts the filesystem while it writes, and if one fails partway the module serves a built-in recovery page at `/` where you can upload again, so a bad web UI flash does not strand the unit.

> [!NOTE]
> USB remains the way to do a first flash or to recover a module that will not boot. OTA is for modules already running v9.

---

## Building from source

```sh
pio run -e esp32c6 --target upload       # build and flash over USB
pio run -e esp32c6-release                # release build, debug output off
pio run -e esp32c6-release -t buildfs     # web UI image
python scripts/merge_firmware.py --build-dir .pio/build/esp32c6-release
pio test -e native                        # host test suite, no hardware needed
```

`tools/mock_ui_server.py` serves the web UI from `data/` against a fake API, so you can work on the UI in a desktop browser with no module attached.

CI builds, tests and packages each tagged release, and publishes the update feed that the Update tab reads.

---

## PCB and enclosure

The Gerbers, schematic, BOM and 3D model are in [`PCB/`](PCB/), and the enclosure STLs in [`Enclosure/`](Enclosure/), as published by Forbes Automotive. Use them to make your own units if you wish. Pinout and function stay the same across the supported enclosure versions.

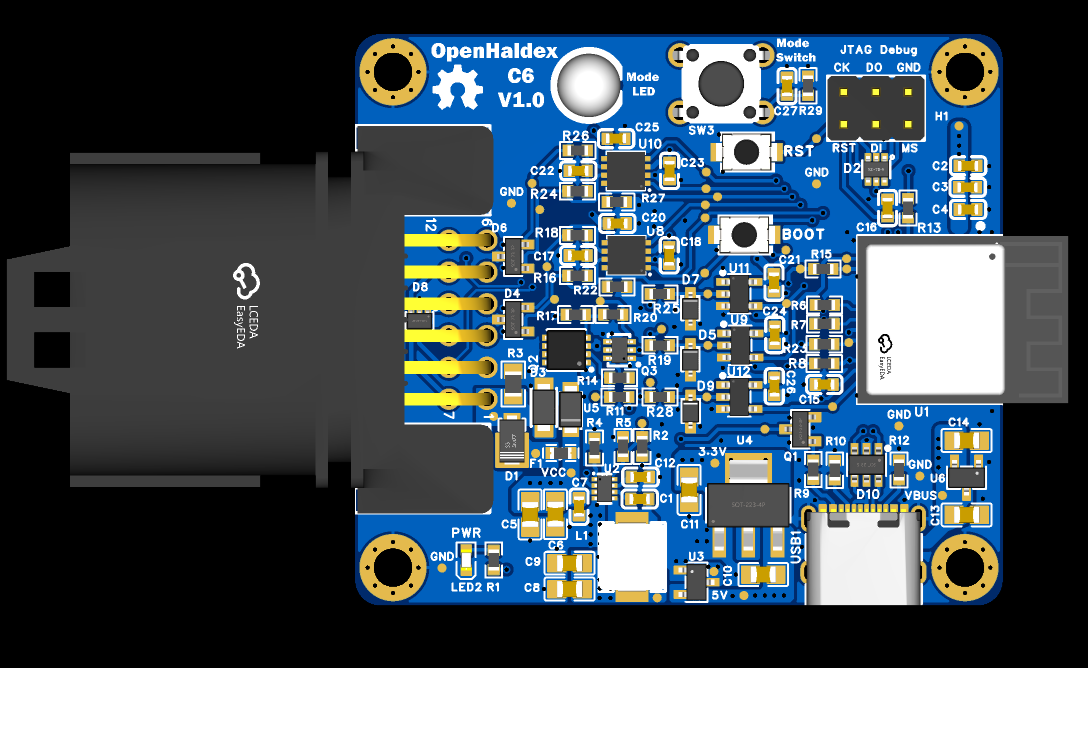
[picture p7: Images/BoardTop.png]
OpenHaldex-C6 PCB, top

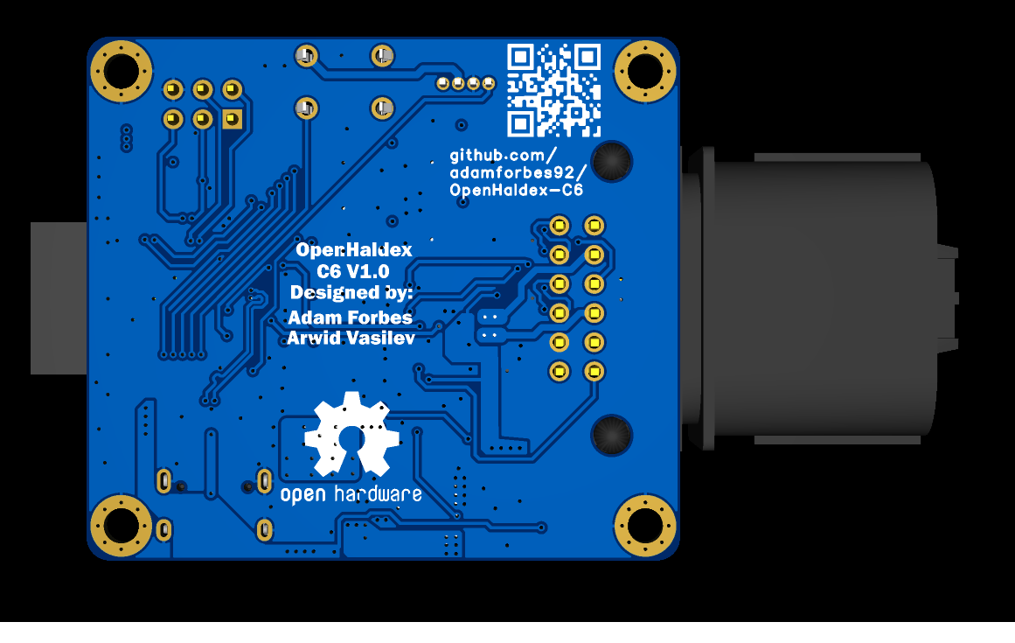
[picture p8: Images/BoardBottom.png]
OpenHaldex-C6 PCB, bottom


Assembled modules are available from Forbes Automotive: **[OpenHaldex C6 Controller](https://forbes-automotive.com/products/openhaldex-controller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)**.

---

## Acknowledgements

- **Forbes Automotive** - the OpenHaldex-C6 platform: the reverse engineering and open-source implementation for Gen2, Gen4 and Gen5 Haldex systems, the hardware, and the continued work on all of it. Edge exists because of it.
- **louij2** (Luca C) - Home WiFi bridge mode, Backup & Restore and Bench Mode (upstream PR #39).
- **danati** - Bluetooth LE for the DashCAN app, bigger OTA slots and the lock-release fix (upstream PR #44).
- **A Banging Donk** - [the original OpenHaldex project](https://github.com/ABangingDonk/OpenHaldexT4) for Gen1 vehicles.
- **Chris "meatro" (SpringfieldVW)** - [OpenHaldex-S3](https://github.com/meatro/OpenHaldex-S3) (MIT), the origin of the CAN analyzer / GVRET (SavvyCAN) tooling and parts of the map editor. See [THIRD_PARTY_NOTICES.md](THIRD_PARTY_NOTICES.md).
- **Arwid Vasilev** - PCB redesign (V1.02).
- **LVT Technologies** - OTA update integration (now deprecated, still appreciated).

---

## Upstream

Edge keeps Forbes's history and tracks **[Forbes-Automotive/OpenHaldex-C6](https://github.com/Forbes-Automotive/OpenHaldex-C6)** as its upstream. To pull their changes:

```sh
git remote add upstream https://github.com/Forbes-Automotive/OpenHaldex-C6.git
git fetch upstream
git merge upstream/main
```

For assembled hardware, official firmware and support, go to the upstream project and [Forbes Automotive](https://forbes-automotive.com/). Their updater page flashes their build, not Edge's.

Edge's firmware is built on upstream V9.00.6 (through Forbes commit 1a61999). The Forbes `Releases/` binary folder and Discord workflow are not part of this repo; Edge publishes through tagged GitHub releases. Third-party attribution from the shared lineage is in [THIRD_PARTY_NOTICES.md](THIRD_PARTY_NOTICES.md).

---

## Licensing

OpenHaldex Edge is open source under the [MIT License](LICENSE.md), the same licence as upstream. The firmware, web UI, tools and hardware design files are published so you can build, inspect, modify, redistribute and fabricate a controller for any purpose, commercial use included, as long as you keep the copyright and licence notices.

- Forbes Automotive's original code and hardware design files: MIT, copyright Forbes Automotive.
- Edge's own additions: the same MIT terms, copyright Kile Thomson.
- Portions derived from OpenHaldex-S3 (meatro): MIT, notice preserved.
- The original OpenHaldex (Gen1, ABangingDonk): see [THIRD_PARTY_NOTICES.md](THIRD_PARTY_NOTICES.md).

If you redistribute source or binaries, keep LICENSE.md and THIRD_PARTY_NOTICES.md with them.

---

## Disclaimer

> [!CAUTION]
> This device modifies Haldex behaviour and should only be used **off-road or on a closed course**.
>
> The unit may behave unpredictably and could increase drivetrain wear.
>
> **Use at your own risk.** Forbes Automotive and the Edge contributors are not responsible for damages resulting from the use of this device or software.

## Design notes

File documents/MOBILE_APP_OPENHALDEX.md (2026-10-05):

# OpenHaldex-C6 BLE contract (DashCAN mobile app)

Canonical copy: this file in the OpenHaldex-C6 repo. The DashCAN app keeps a mirror in its `docs/`. Change this file
first and copy it over.

Contract version: `protoVersion` 1, Status layout 1. Implementation: `src/OpenHaldexC6_BLE.cpp`.

## Overview

The OpenHaldex-C6 is a BLE peripheral that the DashCAN app connects to **in addition to** a DashCAN unit. The
OpenHaldex has its own UUIDs and name, and does not use the DashCAN text protocol (`GFW`, `CAN<ids>.`, ...).

The contract is GATT-native: every setting is a characteristic (read / write / notify), and live data is a single
packed binary Status characteristic. There are no text commands and no message reassembly.

Scope:
- change the mode;
- switch the controller on/off;
- read the live data shown on the web UI dashboard.

Everything else (Expert map, learn, force modes, generation, WiFi, OTA) stays on the web UI. There is no firmware
update over BLE.

## Advertising

| Part | Content |
|---|---|
| Advertising packet | flags (LE General Discoverable, BR/EDR not supported) + complete list of 128-bit services: the OpenHaldex service UUID |
| Scan response | complete local name `OpenHaldex-XXXX` (`XXXX` = last 2 bytes of the BT MAC, upper-case hex) |

- **Identify the device by the service UUID.** The name never contains `DashCAN`, so the DashCAN auto-connect ignores
  it.
- **Up to two links.** The device keeps advertising while a slot is free. A phone whose app was closed or killed can
  leave its old link open at the OS level; a new link from the same phone (identity address) drops the older one, so a
  restarted app can always reconnect without rebooting the OpenHaldex.
- **BLE is off when:**
  - the user disables it (web UI → Settings → Bluetooth);
  - the controller is in low-power mode (car parked, WiFi AP off). It comes back when CAN traffic returns. A
    connected phone does not keep the controller awake.

## GATT

Service `6254A001-C7B7-494F-A2FB-76FB74A7DDF0`:

| Characteristic | UUID | Properties | Value |
|---|---|---|---|
| Mode | `6254A002-C7B7-494F-A2FB-76FB74A7DDF0` | read, write (with response), notify | `u8` mode |
| Controller | `6254A003-C7B7-494F-A2FB-76FB74A7DDF0` | read, write (with response), notify | `u8` 1 = enabled, 0 = disabled |
| Status | `6254A004-C7B7-494F-A2FB-76FB74A7DDF0` | read, notify | 17 bytes, see [Status](#status) |
| Info | `6254A005-C7B7-494F-A2FB-76FB74A7DDF0` | read | `u8 protoVersion`, `u8 haldexGeneration`, `u8 isStandalone` |
| Settings | `6254A006-C7B7-494F-A2FB-76FB74A7DDF0` | read, write (with response), notify | 14 bytes, see [Settings](#settings); write `[u8 id][value]` |
| Diag | `6254A007-C7B7-494F-A2FB-76FB74A7DDF0` | read, notify | 20 bytes, 1 Hz, see [Diag](#diag) |
| Pairing | `6254A008-C7B7-494F-A2FB-76FB74A7DDF0` | read (encrypted) | `u8 codeRequired`, `u32 pairingCode`, see [Pairing](#pairing) |

**GATT cache:** phones cache the attribute table of bonded devices. The firmware sends a Service Changed indication
every time BLE starts, so after a firmware update that adds characteristics a bonded phone re-discovers on its next
connection. If a phone still reads wrong values (e.g. it was bonded to a pre-release build without that indication),
forget the device in the phone's Bluetooth settings once. On Android the app can also call `refreshCache` before
discovery.

Mode values: `0` Stock, `1` FWD, `2` 50:50, `3` 60:40, `4` 75:25, `5` Expert.

Info `haldexGeneration` values:

| Value | Platform |
|---|---|
| `1`, `2`, `4` | VW PQ |
| `41` | GM/SAAB Gen4 |
| `42` | Ford |
| `50` | Gen5 MQB 0CQ |
| `51` | Gen5 PQ 0AY |
| `52` | Gen5 MQB 0CQ VAQ |

Device Information Service `0x180A` (read):

| Characteristic | Value |
|---|---|
| `0x2A29` Manufacturer Name | `Forbes Automotive` |
| `0x2A24` Model Number | `OpenHaldex-C6` |
| `0x2A26` Firmware Revision | firmware version, e.g. `9.00.0` |

## Security

- **Pairing: trust on first use.** LE Secure Connections with bonding.
  - **While no phone is bonded** (new unit, or after Forget Paired Phones) pairing is "Just Works"
    (`NoInputNoOutput`, no MITM): no code, the phone at most asks the user to confirm.
  - **Once a phone has bonded**, the device switches to passkey pairing (`DisplayOnly`, MITM): a new phone must enter
    the **6-digit pairing code**. The code is random, persisted, shown on the web UI (Settings → Bluetooth) and readable
    by a paired phone from the [Pairing](#pairing) characteristic, so the app can show it for a second phone.
    Phones bonded before stay valid without it. A new pairing that does not use the code is refused (bond deleted,
    link dropped).
  - **Forget Paired Phones** deletes all bonds, makes a new code and opens pairing for the next phone again.
- **Writes need an encrypted (bonded) link.** The first write to Mode or Controller from an unpaired phone fails with
  an insufficient-encryption/authentication error, which makes iOS and Android pair (confirm dialog for the first
  phone, code entry after that). The app should retry the write after pairing succeeds; on Android it can call
  `createBond` first.
- **Reads and notifications are open** (Status, Info, Mode, Controller, DIS), so live data works without pairing.
- **Forget Paired Phones** in the web UI deletes all bonds; phones must pair again (the phone should also forget
  the device in its Bluetooth settings).

### Pairing

`6254A008-C7B7-494F-A2FB-76FB74A7DDF0`, read only, **encrypted read** (an unpaired phone pairs first). 5 bytes:
`u8 codeRequired` (0 = no phone bonded yet, 1 = new phones need the code), `u32 pairingCode` little-endian
(100000..999999). Optional like Settings / Diag: check that the characteristic is present. Reading it from an
unpaired phone starts pairing, so an app should read it only once the phone is paired (or on a user action).

## Writes: request, then echo

A write to Mode or Controller is a **request**. After processing it the device sets the characteristic to the value
actually in effect and **notifies** it (Mode and Controller are both notified). The app shows the notified value, not
the value it wrote.

| Write | Result |
|---|---|
| Mode `n`, 0 ≤ n ≤ 5, controller enabled | mode = `n` |
| Mode `0` (Stock) while standalone | the mode stays at the last driving mode (Stock is passthrough-only) |
| Mode while the controller is disabled | rejected, mode stays Stock |
| Mode > 5 | rejected, unchanged |
| Controller `0` | controller disabled, mode forced to Stock |
| Controller `1` | controller enabled (also leaves SavvyCAN analyzer mode, as the web UI does) |
| Controller > 1, or any write whose length ≠ 1 byte | rejected, unchanged |

- **Timing:** writes are applied within about 50 ms. The echo notify arrives right after.
- **No error codes:** the write response is always success once the link is paired. A rejection is visible only
  because the echoed value differs from the value written.
- **Changes from other sources are notified too:** the web UI, the physical buttons, CAN `0x6A0` and force modes all
  produce a Mode/Controller notify within about 50 ms.

## Status

Notified at 10 Hz while the phone has notifications enabled on Status. It can also be read at any time.
Little-endian:

| Offset | Type | Field | Unknown |
|---|---|---|---|
| 0 | u8 | layout version (= 1) | - |
| 1 | u8 | sequence counter (wraps; lets the app detect dropped notifies) | - |
| 2 | u8 | mode (0..5) | - |
| 3 | u8 | controller enabled (0/1) | - |
| 4 | u8 | lock target % (0..100) | - |
| 5 | u8 | lock actual %: Haldex engagement as reported by the Haldex | `0xFF` |
| 6 | u16 | vehicle speed, km/h | `0xFFFF` |
| 8 | u8 | throttle / pedal %, 0..100 | `0xFF` |
| 9 | u16 | engine rpm | `0xFFFF` |
| 11 | u16 | boost, the raw value the web UI shows | `0xFFFF` |
| 13 | i16 | steering-wheel angle, 0.1° units, signed | `0x8000` (INT16_MIN) |
| 15 | u16 | flags, see below | - |

**When values are unknown:**
- Speed, throttle, rpm and boost are unknown while the chassis CAN is not healthy.
- Lock actual is unknown while the Haldex CAN is not healthy.
- Real values never use a sentinel: the device clamps them to `0xFE` / `0xFFFE`.

**Steering angle:**
- The value is negative when the VW sign bit is set (PQ `LW_1` 0x0C2 `LW1_LRW_Sign`, MQB `LWI_01` 0x086
  `LWI_VZ_Lenkradwinkel`).
  - **Direction (left/right) of the sign is not yet verified on a car.**
- It is unknown when:
  - the frame is older than 500 ms or missing;
  - the chassis CAN is unhealthy;
  - the platform is GM/Ford (generation 41/42).
- The web UI shows only the magnitude in whole degrees.

**Flags:**

| Bit | Meaning |
|---|---|
| 0 | chassis CAN healthy |
| 1 | Haldex CAN healthy |
| 2 | CAN bus failure |
| 3 | traction control switched off by the driver (TC force-mode trigger); chassis CAN only |
| 4 | ASR switched off; chassis CAN only |
| 5 | hazard lights on (hazard force mode); chassis CAN only |
| 6 | external button force active |
| 7 | brake input active |
| 8 | handbrake input active |
| 9 | Haldex temperature protection; Haldex CAN only |
| 10 | Haldex coupling open; Haldex CAN only |
| 11 | Haldex speed limit; Haldex CAN only |
| 12 | controller in standalone mode |
| 13 | external diagnostic tool detected (live diagnostics paused) |
| 14-15 | reserved, 0 |

**Compatibility rules for the app:**
- Drop a payload shorter than 17 bytes.
- Ignore bytes beyond the ones you know: new fields are only appended.
- A different layout version byte means a breaking change. Show "update the app" rather than decoding.

## Settings

Driving settings that are also on the web UI. An app should check that the characteristic is present after
`retrieveServices` before using it (optional characteristics do not change Info `protoVersion`). Writes need a bonded
link, like Mode.

**Read / notify payload**, little-endian, 14 bytes:

| Offset | Type | Field |
|---|---|---|
| 0 | u8 | layout version (= 1) |
| 1 | u8 | bool flags, below |
| 2 | u8 | TC-off force mode value (0..5) |
| 3 | u8 | hazard force mode value (0..5) |
| 4 | u8 | external-button force mode value (0..5) |
| 5 | u16 | no lock below this speed, km/h (0 = off) |
| 7 | u16 | no lock above this speed, km/h (0 = off) |
| 9 | u8 | no lock below this throttle, % |
| 10 | u16 | lock release rate, %/s |
| 12 | u8 | LED brightness, 0..255 |
| 13 | u8 | reserved flags (0) |

Flags at offset 1: bit 0 TC-off force mode on, 1 hazard force mode on, 2 external-button force mode on,
3 release lock on brake, 4 release lock on handbrake, 5 steering-angle lock scaling, 6 rate-limited lock release,
7 live Haldex diagnostics.

**Write:** one setting per write, `[u8 id][value]`, value little-endian, 1 byte for bool / u8 settings, 2 bytes for
u16 settings:

| Id | Setting | Value |
|---|---|---|
| `0x01` | TC-off force mode on | u8 0/1 |
| `0x02` | TC-off force mode value | u8 0..5 |
| `0x03` | hazard force mode on | u8 0/1 |
| `0x04` | hazard force mode value | u8 0..5 |
| `0x05` | external-button force mode on | u8 0/1 |
| `0x06` | external-button force mode value | u8 0..5 |
| `0x07` | release lock on brake | u8 0/1 |
| `0x08` | release lock on handbrake | u8 0/1 |
| `0x09` | no lock below speed | u16 km/h, clamped 0..300 |
| `0x0A` | no lock above speed | u16 km/h, clamped 0..300 |
| `0x0B` | no lock below throttle | u8 %, clamped 0..100 |
| `0x0C` | steering-angle lock scaling | u8 0/1 |
| `0x0D` | rate-limited lock release | u8 0/1 |
| `0x0E` | lock release rate | u16 %/s, clamped 5..500 |
| `0x0F` | live Haldex diagnostics | u8 0/1 |
| `0x10` | LED brightness | u8 |

- **Request, then echo**, as for Mode: after every Settings write the device notifies the full payload with the
  values in effect. Numbers out of range are clamped; an unknown id, a wrong length, a bool > 1 or a mode value ≥ 6
  is rejected (unchanged, still notified).
- **Changes from the web UI** are notified within about 50 ms.
- **Compatibility:** ids are never reused; new settings get new ids and their fields are appended. Ignore trailing
  bytes and unknown flag bits; a different layout version means "update the app".

## Diag

Haldex live diagnostics, the same values as the web UI diagnostics card. Notified once per second while subscribed;
open (no pairing). Optional like Settings: check that the characteristic is present. Little-endian, 20 bytes:

| Offset | Type | Field | Unit |
|---|---|---|---|
| 0 | u8 | layout version (= 1) | - |
| 1 | u8 | source: 0 none, 1 UDS (Gen5 family), 2 KWP2000 (Gen4 0AY) | - |
| 2 | i16 | clutch temperature (Gen5 clutch, Gen4 plate) | 0.1 °C |
| 4 | i16 | oil temperature (Gen4) | 0.1 °C |
| 6 | i16 | control module temperature (Gen5) | 0.1 °C |
| 8 | i16 | cooling fin temperature (Gen5) | 0.1 °C |
| 10 | u16 | supply voltage | 0.01 V |
| 12 | u16 | clutch (valve) current | mA |
| 14 | u16 | clutch duty / PWM | 0.1 % |
| 16 | i16 | oil pressure (Gen4) | 0.01 bar |
| 18 | i16 | estimated torque (Gen4) | Nm |

- **Unknown:** `0x8000` (i16) / `0xFFFF` (u16) for every field the source does not provide, and for all fields when
  the source is 0.
- **Source 0** when live diagnostics are off (Settings flag bit 7 / web UI), the Haldex CAN is down, an external scan
  tool is detected, analyzer mode is on, or the generation has no decoded values (Gen1/2, GM/Ford). UDS values older
  than 5 s also count as unknown.
- **Compatibility:** fields are only appended; drop shorter payloads, ignore extra bytes, a different layout version
  means "update the app".

## Recommended app connection sequence

1. Scan: pick peripherals whose advertised service UUIDs contain `6254A001-…`. Remember the peripheral id for
   reconnects.
2. Connect, then `retrieveServices`.
3. Read Info (check `protoVersion` == 1), Firmware Revision, Mode and Controller.
4. `startNotification` on Mode, Controller and Status (and Settings / Diag, when present). Do this sequentially, awaiting
   each one: Android rejects parallel CCCD writes.
5. Writes use write-with-response (Mode / Controller: 1 byte; Settings: `[id][value]`). If a write fails with an authentication error, wait for
   pairing to complete and retry once.

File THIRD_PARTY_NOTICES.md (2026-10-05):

# Third-Party Notices

OpenHaldex Edge is a fork of
[Forbes-Automotive/OpenHaldex-C6](https://github.com/Forbes-Automotive/OpenHaldex-C6)
and is distributed under the **MIT License**, the same licence as upstream. See
[`LICENSE.md`](LICENSE.md).

- Portions original to Forbes Automotive are MIT, copyright Forbes Automotive.
- Edge's own additions are contributed under the same MIT terms, copyright
  Kile Thomson. Edge adds no extra conditions to the licence.
- Portions that came from other projects keep their original licences, listed
  below. Where one of those licences differs from the MIT License, the original
  licence governs the portions it applies to.

This file records the projects Edge's lineage derives from, the components taken
from each, and the licence or permission basis relied on. It exists so the
attribution obligations that come with those portions travel with every copy.

---

## 1. Original OpenHaldex (Generation 1)

- **Author / Upstream:** ABangingDonk
- **Project:** OpenHaldex / OpenHaldexT4 - https://github.com/ABangingDonk/OpenHaldexT4
- **License:** No license file is published in the upstream repository, so no
  explicit redistribution grant is on record for this work.
- **Relationship:** The OpenHaldex lineage started from ABangingDonk's original
  OpenHaldex codebase for Generation 1 Haldex control. Gen1 control concepts and
  code descend from this work.

> **Attribution note:** the ABangingDonk OpenHaldexT4 repository does not carry a
> LICENSE file, so the permission basis for redistributing Gen1-derived code is not
> formally documented upstream. Edge credits the original author and does not claim
> a grant that is not on record. Anyone redistributing Gen1-derived portions should
> confirm the permission basis with the original author; if a grant cannot be
> established, the affected portions should be treated accordingly.

---

## 2. OpenHaldex-S3 (SpringfieldVW / Chris "meatro")

- **Author / Upstream:** Chris (GitHub: meatro)
- **Project:** OpenHaldex-S3 - https://github.com/meatro/OpenHaldex-S3
- **License:** MIT License (full text below)
- **Relationship:** On 2026-02-08, upstream commit `a4dc321` ("S3 port onto C6")
  imported work derived from OpenHaldex-S3 into the C6 lineage. Derived / ported
  components include, in whole or in part:
  - CAN analysis / GVRET / SavvyCAN-style tooling (CAN View); Edge carries this as
    the analyzer path in `src/OpenHaldexC6_Analyzer.cpp`
  - portions of the map editor / Expert mode, web UI structure and API control, as
    credited in the upstream README

> MIT requires that the copyright notice and permission notice below be retained in
> all copies or substantial portions of the derived code. These portions remain
> available under MIT.

### MIT License (OpenHaldex-S3)

```
MIT License

Copyright (c) 2026 SpringfieldVW.com

Permission is hereby granted, free of charge, to any person obtaining a copy
of this software and associated documentation files (the "Software"), to deal
in the Software without restriction, including without limitation the rights
to use, copy, modify, merge, publish, distribute, sublicense, and/or sell
copies of the Software, and to permit persons to whom the Software is
furnished to do so, subject to the following conditions:

The above copyright notice and this permission notice shall be included in all
copies or substantial portions of the Software.

THE SOFTWARE IS PROVIDED "AS IS", WITHOUT WARRANTY OF ANY KIND, EXPRESS OR
IMPLIED, INCLUDING BUT NOT LIMITED TO THE WARRANTIES OF MERCHANTABILITY,
FITNESS FOR A PARTICULAR PURPOSE AND NONINFRINGEMENT. IN NO EVENT SHALL THE
AUTHORS OR COPYRIGHT HOLDERS BE LIABLE FOR ANY CLAIM, DAMAGES OR OTHER
LIABILITY, WHETHER IN AN ACTION OF CONTRACT, TORT OR OTHERWISE, ARISING FROM,
OUT OF OR IN CONNECTION WITH THE SOFTWARE OR THE USE OR OTHER DEALINGS IN THE
SOFTWARE.
```

---

## 3. Forbes Automotive original work

Portions original to Forbes Automotive are the base Edge builds on. They include
the Gen2 / Gen4 / Gen5 reverse engineering and implementation, the live-data
readout, the low-power sleep system, Long Learn and the other Forbes-authored code,
and the hardware design files (Gerbers, schematics, PCB layouts and enclosure
files). Pull requests merged upstream keep their authors' credit: louij2 (Home WiFi
bridge mode, Backup & Restore, Bench Mode, OTA release channels) and danati
(Bluetooth LE for the DashCAN app). All of it is distributed under the **MIT
License**; see [`LICENSE.md`](LICENSE.md).

Edge is a personal project. It is not affiliated with or endorsed by Forbes
Automotive. For assembled hardware, official firmware and support, see the upstream
project and [forbes-automotive.com](https://forbes-automotive.com/).

---

## 4. Edge additions

Edge's own code, web UI, tests and tooling are contributed under the same MIT
terms as upstream, copyright Kile Thomson. Two Edge changes were adopted upstream
with credit: the per-corner slip geometry and the ESP_14 Launch PWM floor.

---

## Summary

- **Edge:** open source under the MIT License, same as upstream, no extra terms.
  Commercial use and redistribution are permitted subject to keeping the copyright
  and licence notices.
- **Upstream lineage:** the ABangingDonk (Gen1) and meatro/OpenHaldex-S3 (analyzer /
  GVRET / SavvyCAN tooling) portions keep their original licence position; the MIT
  notice for the S3-derived portions is preserved above as MIT requires.
- **No warranty.** See the disclaimer in [`README.md`](README.md) and the warranty
  terms in [`LICENSE.md`](LICENSE.md).

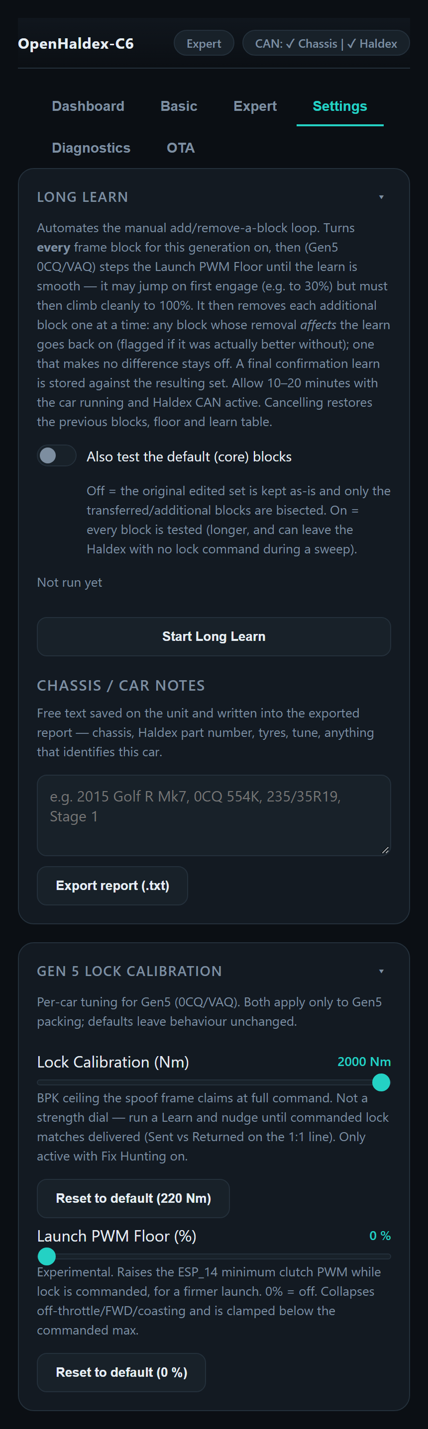
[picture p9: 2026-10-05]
Images/ui-long-learn.png

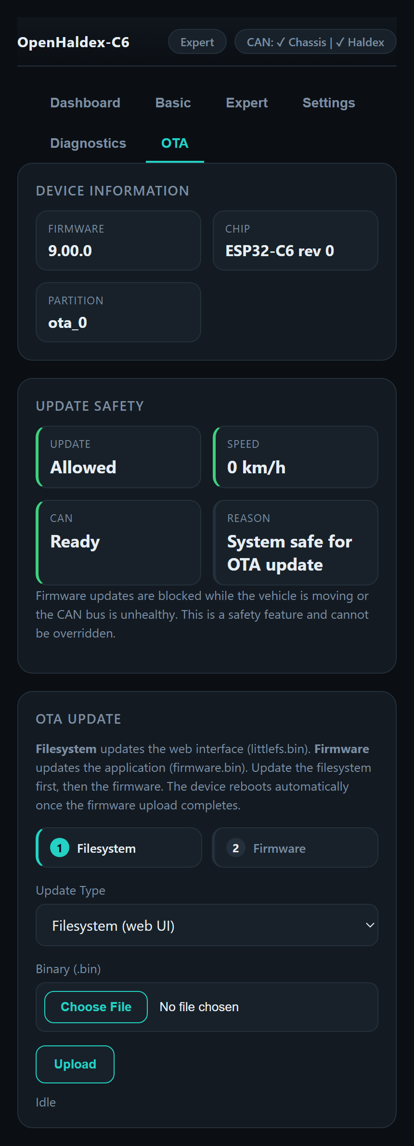
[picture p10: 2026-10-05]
Images/ui-ota.png

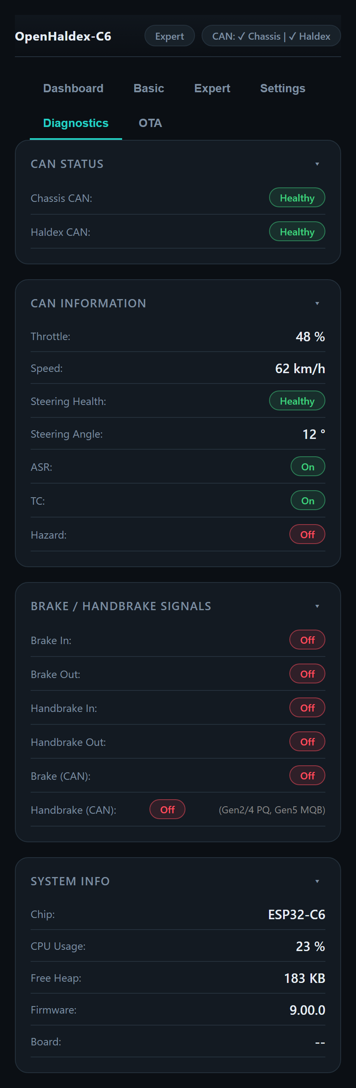
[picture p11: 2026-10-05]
Images/ui-diagnostics.png

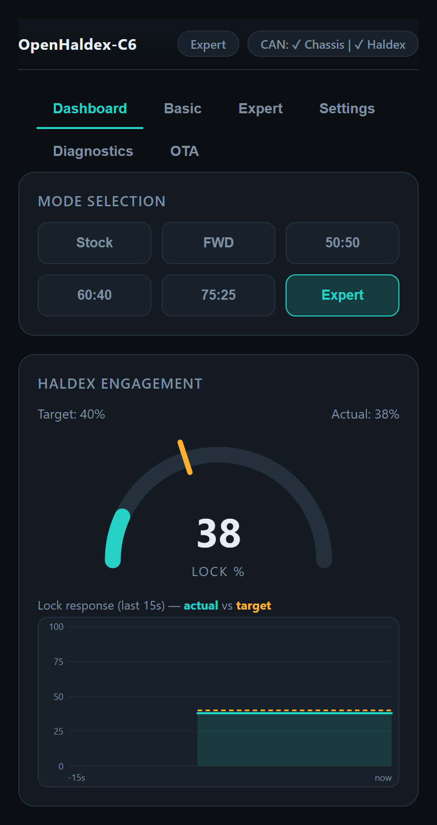
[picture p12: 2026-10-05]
Images/ui-dashboard.png

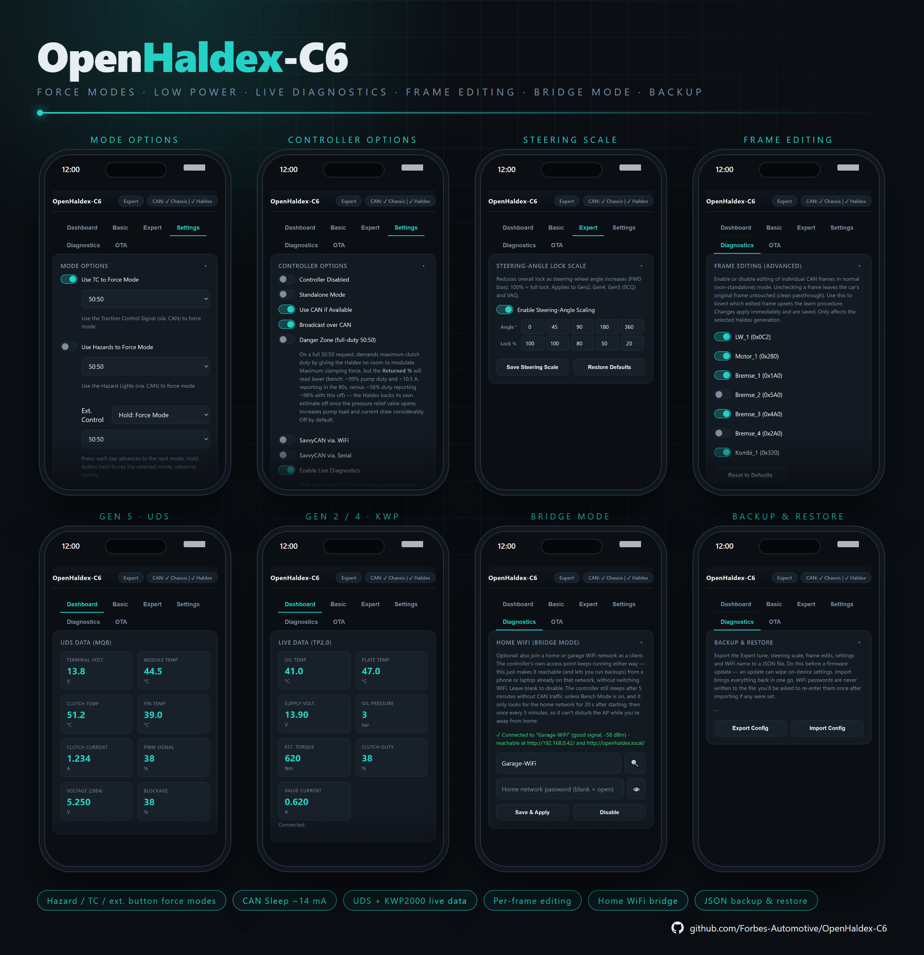
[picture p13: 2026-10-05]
Images/openHaldexUI-2.png

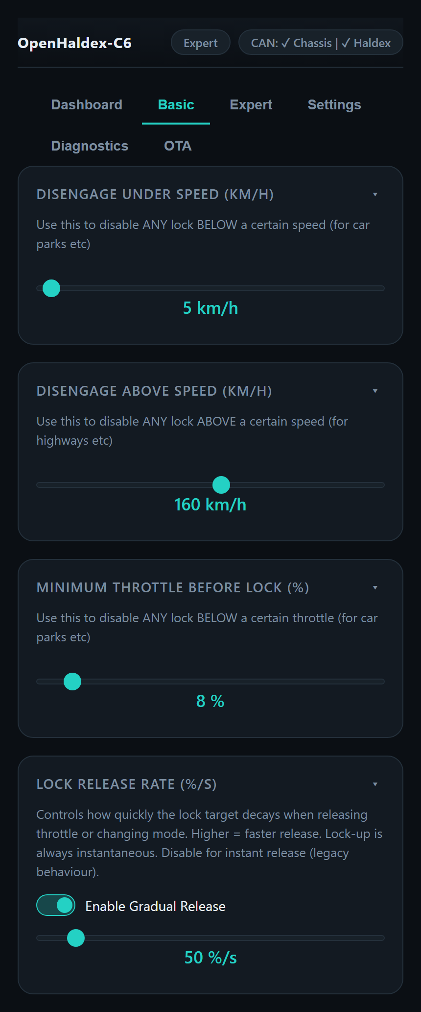
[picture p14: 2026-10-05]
Images/ui-basic.png

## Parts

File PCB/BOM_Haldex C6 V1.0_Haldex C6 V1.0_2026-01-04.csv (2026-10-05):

No. | Quantity | Comment | Designator | Footprint | Value | Manufacturer Part | Manufacturer | Supplier Part | Supplier
1 | 8 | 100nF | C1,C4,C12,C13,C14,C17,C21,C22 | C0603 | 100nF | CL10B104KB8NNNC | SAMSUNG(三星) | C1591 | LCSC
2 | 5 | 22uF | C2,C3,C7,C10,C11 | C0805 | 22uF | HGC0805R5226M350NSLJ | Chinocera(华瓷) | C22367832 | LCSC
3 | 3 | 47uF | C5,C6,C8 | C0805 | 47uF | CL21A476MPYNNWE | SAMSUNG(三星) | C5596752 | LCSC
4 | 1 | 33nF | C9 | C0603 | 33nF | CL10B333KB8NNNC | SAMSUNG(三星) | C21117 | LCSC
5 | 1 | 4.7uF | C15 | C0603 | 4.7uF | CL10A475KP8NNNC | SAMSUNG(三星) | C1705 | LCSC
6 | 1 | 2.2uF | C16 | C0603 | 2.2uF | CL10A225KO8NNNC | SAMSUNG(三星) | C23630 | LCSC
7 | 3 | 1uF | C18,C23,C24 | C0603 | 1uF | CL10B105KB8NQNC | SAMSUNG(三星) | C5199872 | LCSC
8 | 2 | 2.2nF | C19,C20 | C0603 | 2.2nF | CL10C222JB8NNNC | SAMSUNG(三星) | C33353 | LCSC
9 | 1 | SS3P3-M3/84A | D1 | DO-220AA_L3.4-W2.0-LS3.9-RD |  | SS3P3-M3/84A | VISHAY(威世) | C2920641 | LCSC
10 | 1 | SMF24CA | D2 | SOD-123FL_L2.8-W1.8-LS3.7-BI |  | SMF24CA | 晶导微电子 | C353294 | LCSC
11 | 1 | USBLC6-2SC6 | D3 | SOT-23-6_L2.9-W1.6-P0.95-LS2.8-BL |  | USBLC6-2SC6 | UMW(友台半导体) | C2687116 | LCSC
12 | 3 | BZT52C4V7S | D4,D6,D7 | SOD-323_L1.8-W1.3-LS2.5-RD |  | BZT52C4V7S | 晶导微电子 | C353517 | LCSC
13 | 1 | SMF12CT1G | D5 | SOT-363_L2.0-W1.3-P0.65-LS2.1-BR |  | SMF12CT1G | TECH PUBLIC(台舟) | C2999118 | LCSC
14 | 1 | SMF05C | D8 | SC-70-6_L2.0-W1.3-P0.65-LS2.1-BR |  | SMF05C | TECH PUBLIC(台舟) | C558425 | LCSC
15 | 2 | PESD2CAN | D9,D10 | SOT-23-3_L2.9-W1.3-P1.90-LS2.4-BR |  | PESD2CAN | TECH PUBLIC(台舟) | C907830 | LCSC
16 | 1 | SMF24A | D11 | SOD-123FL_L2.7-W1.8-LS3.8-RD |  | SMF24A | R+O(宏嘉诚) | C19077514 | LCSC
17 | 1 | 0467001.NRHF | F1 | F0603 |  | 0467001.NRHF | Littelfuse(美国力特) | C151139 | LCSC
18 | 1 | 2.54-2*3 | H1 | HDR-TH_6P-P2.54-V-R2-C3-S2.54_A2541WV-2X3P |  | 2.54-2*3 | ZHOURI(洲日) | C5116479 | LCSC
19 | 1 | 3.3uH | L1 | IND-SMD_L5.4-W5.2_RS0530 | 3.3uH | RS0530-3R3MS | Ruishen(瑞申电子) | C32712971 | LCSC
20 | 1 | XL-1608UGC-04 | LED1 | LED0603-RD_GREEN |  | XL-1608UGC-04 | XINGLIGHT(成兴光) | C965804 | LCSC
21 | 1 | WS2812D-F5 | LED2 | LED-TH_4P-BD5.8-P1.30 |  | WS2812D-F5 | worldsemi | C190565 | LCSC
22 | 1 | MX23A12NF1 | P1 | COON-TH_MX23A12NF1 |  | MX23A12NF1 | JAE(日本航空电子) | C5359486 | LCSC
23 | 1 | AGM30P14MBP | Q1 | DFN-8_L3.2-W3.1-P0.65-LS3.4-BL-1 |  | AGM30P14MBP | AGMSEMI(芯控源) | C5367089 | LCSC
24 | 1 | 2N7002DW | Q2 | SOT-363-6_L2.0-W1.3-P0.65-LS2.1-BL |  | 2N7002DW | Hottech(合科泰) | C5190214 | LCSC
25 | 6 | 1kΩ | R1,R8,R9,R11,R13,R16 | R0603 | 1kΩ | 0603WAF1001T5E | UNI-ROYAL(厚声) | C21190 | LCSC
26 | 1 | 280pF@1MHz | R2 | R0805 | 280pF@1MHz | FPV201209E260PKT | FH(风华) | C2991545 | LCSC
27 | 1 | 52.3kΩ | R3 | R0603 | 52.3kΩ | 0603WAF5232T5E | UNI-ROYAL(厚声) | C23198 | LCSC
28 | 3 | 20kΩ | R4,R10,R14 | R0603 | 20kΩ | 0603WAF2002T5E | UNI-ROYAL(厚声) | C4184 | LCSC
29 | 8 | 10kΩ | R5,R12,R15,R17,R20,R25,R26,R27 | R0603 | 10kΩ | 0603WAF1002T5E | UNI-ROYAL(厚声) | C25804 | LCSC
30 | 2 | 5.1kΩ | R6,R7 | R0603 | 5.1kΩ | 0603WAF5101T5E | UNI-ROYAL(厚声) | C23186 | LCSC
31 | 2 | 33Ω | R18,R19 | R0603 | 33Ω | 0603WAF330JT5E | UNI-ROYAL(厚声) | C23140 | LCSC
32 | 4 | 60.4Ω | R21,R22,R23,R24 | R0603 | 60.4Ω | RC0603FR-0760R4L | YAGEO(国巨) | C245987 | LCSC
33 | 1 | TS-1002-07026 | SW1 | SW-TH_4P-L6.0-W6.0-P4.50-LS6.5 |  | TS-1002-07026 | XUNPU(讯普) | C455095 | LCSC
34 | 2 | TS-1088-AR02016 | SW2,SW3 | SW-SMD_L3.9-W3.0-P4.45 |  | TS-1088-AR02016 | XUNPU(讯普) | C720477 | LCSC
35 | 1 | TPS62933DRLR | U1 | SOT-583-8_L2.1-W1.2-P0.50-LS1.6-BR |  | TPS62933DRLR | TI(德州仪器) | C3200405 | LCSC
36 | 2 | CH213K | U2,U5 | SOT-23-3_L2.9-W1.6-P1.90-LS2.8-BR |  | CH213K | WCH(南京沁恒) | C5456874 | LCSC
37 | 1 | AMS1117-3.3 | U3 | SOT-223-4_L6.5-W3.5-P2.30-LS7.0-BR |  | AMS1117-3.3 | UMW(友台半导体) | C347222 | LCSC
38 | 3 | SN74LVC1G17DBVR | U6,U7,U8 | SOT-23-5_L3.0-W1.5-P0.95-LS2.8-BL |  | SN74LVC1G17DBVR | TECH PUBLIC(台舟) | C19829662 | LCSC
39 | 1 | ESP32-C6-MINI-1-N4 | U9 | WIFIM-SMD_61P-L16.6-W13.2-P0.80-ESP32-C6-MINI-1-N4 |  | ESP32-C6-MINI-1-N4 | ESPRESSIF(乐鑫) | C5736265 | LCSC
40 | 2 | TCAN1044VDRBRQ1 | U10,U11 | VSON-8_L3.0-W3.0-P0.65-BR-EP |  | TCAN1044VDRBRQ1 | TI(德州仪器) | C5215851 | LCSC
41 | 1 | TYPE-C 16PIN 2MD(073) | USB1 | USB-C-SMD_TYPE-C-6PIN-2MD-073 |  | TYPE-C 16PIN 2MD(073) | SHOU HAN(首韩) | C2765186 | LCSC

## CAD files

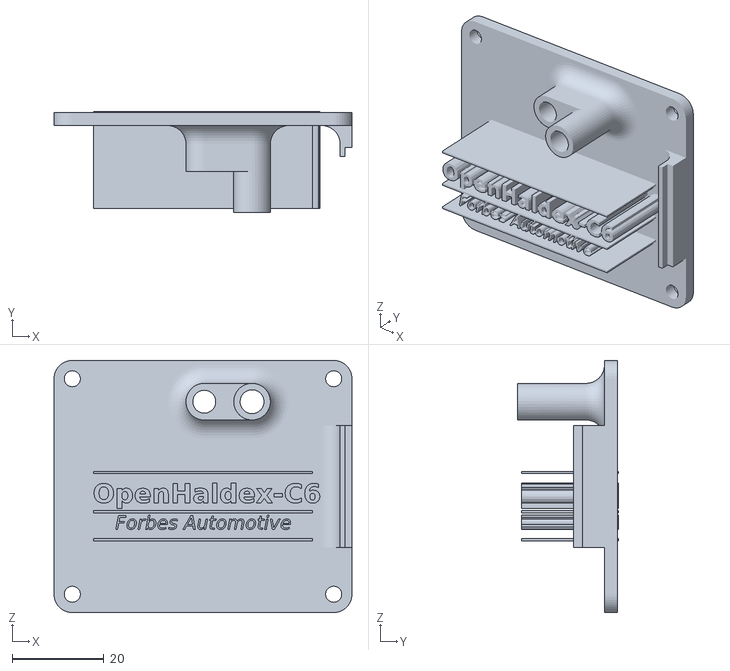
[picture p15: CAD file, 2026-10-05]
Enclosure/HaldexBoxC6_V1_Lid_Recessed.STL
65.0 x 22.1 x 55.0

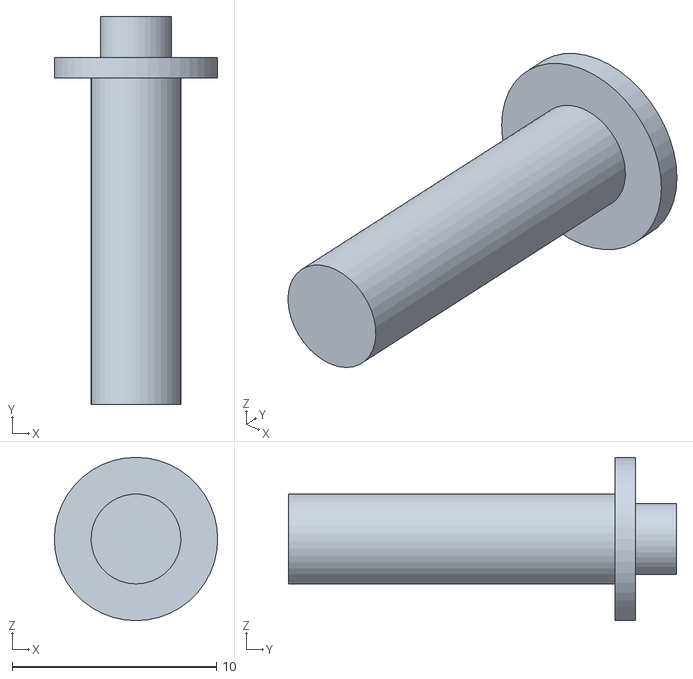
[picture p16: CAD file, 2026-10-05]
Enclosure/HaldexButtonV4.STL
8.00 x 19.0 x 8.00

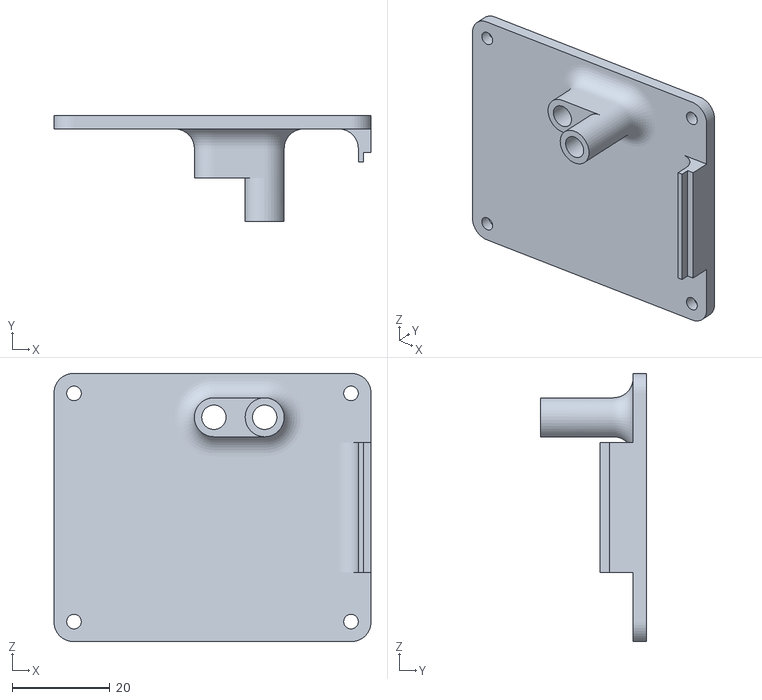
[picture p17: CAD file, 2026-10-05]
Enclosure/HaldexBoxC6_V1_Lid.STL
65.0 x 21.8 x 55.0

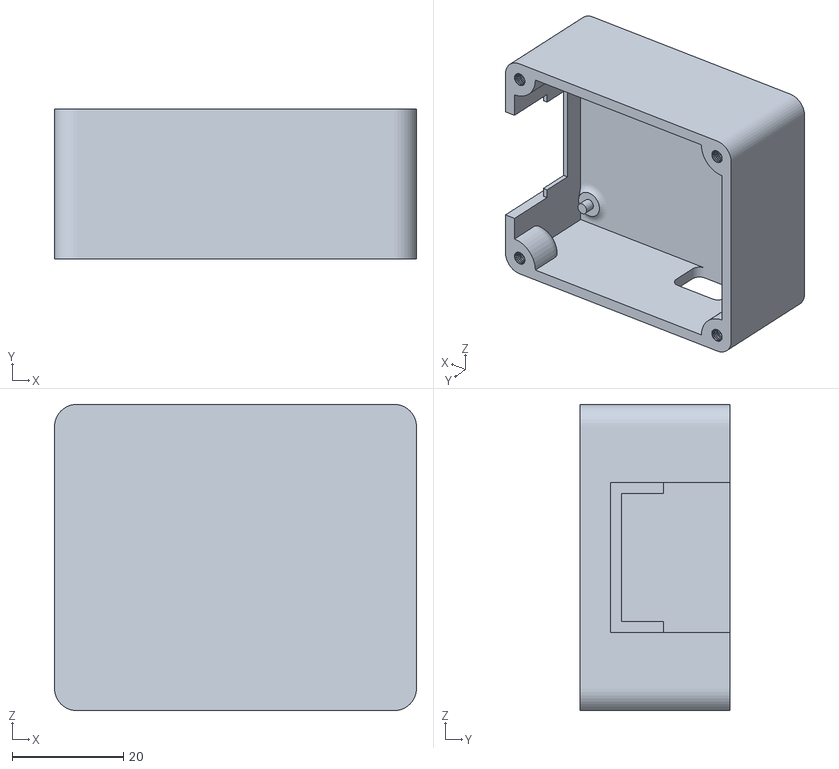
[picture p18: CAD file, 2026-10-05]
Enclosure/HaldexBoxC6_V1.STL
65.0 x 27.0 x 55.0

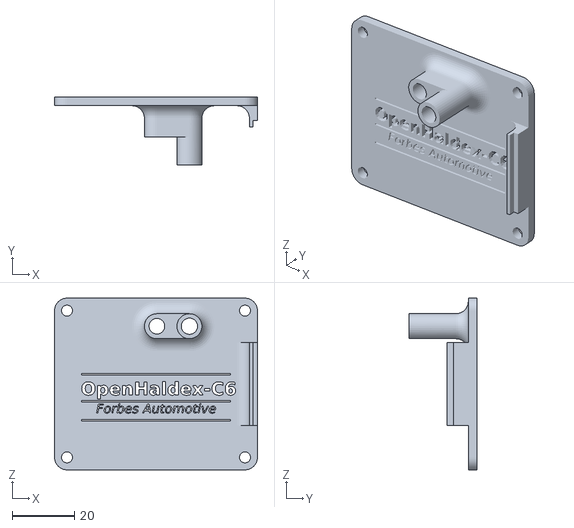
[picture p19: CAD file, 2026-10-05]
Enclosure/HaldexBoxC6_V1_Lid_CutThrough.STL
65.0 x 21.8 x 55.0

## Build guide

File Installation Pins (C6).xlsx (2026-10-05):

Pin Number | Purpose | Comment
1 | 12v Ignition | Supply to module, 12v ignition
2 | Ground | Ground
3 | CAN L | Chassis CAN Low
4 | CAN H | Chassis CAN High
5 | CAN L | Haldex CAN Low
6 | CAN H | Haldex CAN High
7 | Mode Change | 12v switch to change mode
8 | Brake In | Brake signal in (+12v)
9 | Brake Out | Brake signal out
10 | Handbrake In | Handbrake signal in (+12v)
11 | Handbrake Out | Handbrake signal out
12 | N/A | N/A

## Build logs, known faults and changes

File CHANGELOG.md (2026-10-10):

# Changelog

All notable changes to OpenHaldex Edge are listed here.

Edge is a fork of Forbes Automotive's OpenHaldex-C6. From v9.01.0 it is built on
upstream V9.00.6 plus the pull requests merged before it. The v8.00.x entries
further down are the earlier Edge line, built on upstream V8.00.2; they stay as
history. Upstream's own features are Forbes's work and the credited pull request
authors', so they are listed once under v9.01.0 and not repeated version by
version.

---

## v9.01.0-beta3 - 2026-10-11

> Newer build toolchain, smaller AsyncTCP stack, a README brought up to date with upstream V9.00.6, and a fix to the Update tab hint on mobile data. OTA from beta2.

### Updating

beta2 to beta3 is an OTA update. The partition table is unchanged and settings are kept.

### Changed

- Build toolchain: pioarduino platform 54.03.20 to 55.03.312 (Arduino 3.3.12, IDF 5.5.5), as in Forbes's V9.00.6. Building needs PlatformIO Core 6.2.0 or newer. Same code, flash use of the app goes from 1,616,129 to 1,714,022 bytes (88.1% to 93.4% of the 0x1C0000 slot) and RAM from 59,736 to 60,560 bytes.
- AsyncTCP task stack set to 8192 bytes (`CONFIG_ASYNC_TCP_STACK_SIZE`) instead of the 16 KB library default, which frees 8 KB of heap. The `Async TCP` library is ignored so the mathieucarbou one is used.
- README rewritten to match upstream V9.00.6: overview and hardware, purchase link, status LED, the change-mode request and broadcast frame in their own section, low power mode in three layers with the sleep set-up steps, and more detail on live diagnostics and SavvyCAN over USB.

### Fixed

- The Update tab hint and the README disagreed about mobile data. On the module's own WiFi the phone normally keeps mobile data, so the GitHub check works as it is. Home WiFi is the fallback for phones that still drop it, and for updating from a laptop at home.
- README: the low power section said the CPU light-sleeps. Edge turns automatic light sleep off on purpose; the text now says so.

---

## v9.01.0-beta2 - 2026-10-10

> Merges Forbes's V9.00.6: BLE boot-loop fix, much less RAM, a faster per-block Long Learn, sleep auto-setup and ESP-NOW gauges. An OTA update from beta1.

### Updating

beta1 to beta2 is an OTA update. The partition table (`src/partitions_4mb.csv`) is unchanged, so use the update page (merged image or release channel) and no USB flash is needed. Settings are kept: the new keys default on first boot.

### Added

From upstream V9.00.6 and V9.00.5 (Forbes Automotive):

- **Boot-loop guard for Bluetooth.** If the Bluetooth controller fails to start (the C6 logs `ble ll env init error code:-13`), Bluetooth stays off until the next reboot and the rest of the module carries on. Before, the module crashed about a second after WiFi came up. Free heap is logged just before the start.
- **Long Learn reworked.** The lock-driven blocks are always sent (an optional switch tests them too). All blocks on must give a smooth 100% sweep first, and two reads at 20, 40, 70 and 100% lock set a noise level. Each extra block is then switched off on its own and read at those points (before, blocks were removed one after another and judged against a shrinking set). A confirmation sweep with all the no-effect blocks off together must match, or every block is left on and the run is flagged. If the reference is not smooth or too noisy the run stops with a reason. About 6 to 8 minutes on Gen5. The Gen5 BPK step is kept, and the packing and ceiling it settles on are kept when the run finishes.
- **Sleep auto-setup.** An armed module waits for the car to be left parked (ignition off, read from Klemmen_Status_01), measures the chassis frame rate for 15 minutes, sets the wake threshold just above it and turns CAN Sleep on. New switch under CAN Sleep on the Settings tab.
- **Gauges over WiFi (ESP-NOW).** Live state broadcast for a Forbes can2gauge CAN gauge, plus signed commands (mode, generation, learn, controller on and off). The signing key is the WiFi password. Two switches in a new card on the Diagnostics tab, both on by default.
- **Danger Zone through the torque request.** The pump duty on the 0CQ follows the Motor_11 torque, so Danger Zone now raises that ceiling to 320 Nm (serial lab `DANGERNM`) at a full lock request. It no longer pins the ESP_14 Min band.
- **Pump voltage (UDS 0x2BE9)** is read as little-endian, 0.1 V per count. The old reading showed an impossible 20.5 V.

### Changed

- **Less RAM.** The Freenove WS2812 library (a 24 KB static LED buffer for one LED) is replaced by a small `OneLed` class on the core's LED writer. The ten standalone frame tasks are one scheduler task. Task stacks were resized from measured use (updateTriggers 3072, broadcastOpenHaldex 2048). `debugMemory` logs heap and per-task stack headroom in developer builds; release builds keep it off.
- The Long Learn tracker and report on the web UI show the new phases, the per-block deviation, the noise level and the stop reason.
- Line endings are LF in the repo (upstream #49).

### Kept from Edge

CAN queues at 128 and 64 frames, the state mutex around every frame builder (the scheduler takes it for each one), the speed interlock and restore-on-abort in Long Learn, Edge's drive-mode fix on generation change, the light-sleep lock, Stock passthrough, the web access rules, map slots, one-file OTA, Edge's web UI, icons and manifest, and platform 54.03.20.

### Not taken

Forbes's `Releases/` binaries (Edge publishes through tagged GitHub releases), the Discord workflow, upstream's themes, and the AsyncTCP stack cut that upstream's notes mention but never put in `platformio.ini`.

---

## v9.01.0-beta1 - 2026-10-06

> Edge rebuilt on Forbes V9: Home WiFi, Bluetooth for DashCAN, Long Learn, Backup & Restore, OTA from GitHub, plus Edge's UI and safety work. First v9 flash is over USB.

### Added

From upstream V9.00.0 and its follow-up pull requests, now part of Edge (credit to
Forbes Automotive, and to louij2 and danati for their pull requests):

- **Long Learn** (Calibrate tab). Automated frame-block learning: a baseline sweep
  with every block on, Gen5 torque-ceiling remediation when the baseline is not
  smooth, then each extra block removed one at a time, and a confirmation sweep on
  the final set. Live tracker, chassis notes saved on the unit and a `.txt` report.
- **Frame blocks.** Switch individual edited CAN frames on or off per generation,
  with Reset to Defaults.
- **Gen5 VAQ** (generation 52), and Gen2/Gen4 handbrake read from CAN.
- **Live Diagnostics** with KWP2000 over TP2.0 for Gen2/Gen4 next to UDS for Gen5.
  It pauses itself while a VCDS/ODIS-style tool is on the bus.
- **Home WiFi (bridge mode).** The module can also join a home or garage network as
  a client. The scan is asynchronous, and it looks for the home network for 20 s
  after starting, then once every 5 minutes (louij2, PR #39).
- **Backup & Restore** on the Diagnostics tab and `tools/openhaldex_config.py`:
  export and import the Expert tune, map slots, frame blocks, settings and WiFi
  names as JSON. Passwords are never written to the file (louij2, PR #39).
- **Bench Mode.** Holds the WiFi up on the bench. It clears itself when either CAN
  bus shows traffic and cannot be switched on while CAN is live (louij2, PR #39).
- **Bluetooth LE for the DashCAN app.** Live data, mode and controller on/off,
  driving settings and Haldex diagnostics from the phone, with first-phone-free
  pairing and a 6-digit code for later phones (danati, PR #44).
- **Update tab with Update from GitHub.** Check for releases, pick a version,
  stable / Latest build channels, optional beta and older versions, six-stage
  progress, rollback warnings (PR #43). Rollback protection on the new firmware, and
  a recovery page when the web UI will not mount.
- **PCB, enclosure, BOM and documents** folders are now in this repo, as published
  by Forbes Automotive.

Added by Edge for v9.01.0:

- **Web access rule for the home network.** A browser reaching the module through
  your router must sign in: user `admin`, password the WiFi password, on every page
  and every `/api` and `/ota` request. The module's own access point stays open to
  anything that joined it.
- **First-run password.** A fresh unit shows only a setup page until a WiFi password
  of 8 to 64 characters is set. There is no open-network option afterwards.
- **Analyzer gate.** Host-to-CAN injection from SavvyCAN is refused until the
  password is set, and for any client that came in through the home network.
- **Phone connectivity probes get a bare 404**, so a phone keeps its mobile data
  while joined to the car.
- **Update from a File takes one file.** `/ota/update` classifies the upload: the
  merged image (split by flash offset into the app slot and web UI partition), a
  bare `firmware.bin`, or a bare `littlefs.bin`. Offsets come from the running
  partition table. Bootloader, partition table and settings bytes in a merged file
  are never written.
- **Map slots on the module.** `/api/maps`, `/api/maps/get`, `/api/maps/save` and
  `/api/maps/delete`: five named slots, with the same checks as `/api/tune`.
- **Car geometry card** on the Calibrate tab: wheelbase, front and rear track,
  steering ratio and the speed floor for the per-wheel slip readout, with the Audi
  TT Mk3 defaults and a reset. The values are included in backups.
- **Release publishing.** CI builds, tests, and publishes each tag to GitHub
  Releases and to the update feed on the `ota` branch, using the `> ` line under
  the version heading in this file as the release notes.
- **Settings keys** `forceModesPriority` and `boardRev` in `/api/settings`.

Carried forward from Edge v8 into the v9 base (details under each v8.00.x entry
below): the restyled dark UI with the live gauge, lock trace and connection badge;
the Expert 3D surface and curve view; Calibrate tab with the not-calibrated
banner; Launch PWM floor and per-car torque ceiling; lock engage and release ramps
in milliseconds; steering-angle lock taper; per-corner slip and drive mode over the
diagnostic channel; the learn interlock (refused above 5 km/h, previous table
restored on cancel); stale CAN inputs failing safe; CAN bus-off recovery; the
mutex around shared control state; installable PWA and full-screen toggle; the
host-runnable test suite and the release build profile.

### Changed

Differences from Edge v8 that you will notice:

- **The speed window now gates every lock path.** Disengage under speed, disengage
  above speed and minimum throttle apply to force modes (TC, hazards, external
  button) and to Expert mode. On Edge v8 those bypassed it.
- **New flash layout, one USB flash.** The Bluetooth release made the app slots
  larger (0x1C0000 each) and the web UI partition smaller (0x70000 at 0x390000).
  A partition table cannot change over the air, so a unit on Edge v8, or on an
  upstream build from before the Bluetooth release, takes v9 once over USB. A
  merged-image flash also blanks the settings area (expected from esptool's
  padding, not yet checked on a unit). The README shows how to flash the separate
  parts instead, which leaves the settings area at 0x9000 alone.
- **Settings keep their names.** The single `openhaldex` NVS namespace and its key
  names are unchanged, so Edge v8 settings are read as they were. The v8 steering
  taper (start, full, floor) is converted into upstream's five-point breakpoint
  curve, which is now the one implementation; a fresh unit starts with that curve
  on (100% to 45 deg, 80% at 90, 50% at 180, 20% at 360). A stock upstream unit is
  migrated once from its old per-key namespaces.
- **From the home network the UI asks for a login** (see above). The Update tab,
  the backup tool and `curl` need `admin` and the WiFi password there.
- **The AP password card no longer offers an open network.** Saving a new password
  restarts the access point. The long press on the mode button clears the password
  and the SSID back to the default and puts the unit into first-run setup mode.
  `/api/wifi/reset` answers 409.
- **One lock ramp.** The millisecond engage and release ramps are the mechanism.
  Upstream's `lockReleaseRatePerSec` (web and the DashCAN settings characteristic)
  maps onto the release ramp, so both front doors work.
- **Update endpoints.** The web UI image goes to `/ota/update/fs` (v8 used
  `/ota/updatefs`). The SHA-256 query on uploads is no longer used: the chip checks
  the firmware image and the filesystem is checked by mounting it. The Software
  Update card moved from Settings to the Update tab as "Update from a File".
- **Live Diagnostics replaces the UDS toggle** and covers UDS and TP2.0. It is off
  by default.
- **Default correction factor without a learn table** stays Edge's (lock + 20)/2,
  which matches the fit in the source comment (upstream computes lock/2 + 20; an
  upstream pull request lines them up). The E2E checksum DataID position follows
  upstream's, verified against a capture.
- **Learn no longer forces BPK packing.** The table is measured under the unit's own
  Fix Hunting setting. The v9 UI has no Fix Hunting switch; Long Learn tries it on
  Gen5 when the baseline is not smooth.

### Fixed

- **Update uploads no longer end the request early.** The upload callbacks used to
  answer 200 on every chunk, which closed the connection mid-upload and could crash
  the web server. The outcome is now sent once after the body (upstream engine,
  kept). A short merged file is refused before anything is erased, and a half
  written filesystem is erased so it cannot mount.
- **CAN Sleep now gates the WiFi shutdown** as well as the CPU scaling, so switching
  it off keeps the WiFi up (louij2, PR #39).
- **Gen5 VAQ** is accepted by the settings API and its frames run in normal mode
  (Forbes, V9.00.0).
- **The lock-release fix** from the Bluetooth pull request (danati, PR #44).
- **The access point hands out no gateway or DNS** (Forbes, V9.00.0), compatible
  with the phone-probe 404 above.

### Notes

- The v9 firmware is built on upstream; Edge's firmware changes are ported onto it
  rather than the other way round. `include/OpenHaldexC6_ver.h` has the V9.01.0
  block.
- Not carried over from upstream: the `Releases/` folder of Forbes binaries (Edge
  publishes through tagged releases) and the Discord workflow. Upstream's dial
  gauge customiser, steering lock-scale table editor and 3D lock map card are not
  in Edge's UI; Edge has its own steering taper and 3D expert map.
- This branch has been built and host-tested. Bench and in-car checks of the v9
  build are still to do, and a USB flash from Edge v8 has not been run on a unit.

---

## v8.00.18 - 2026-09-17

### Added

- **THIRD_PARTY_NOTICES.md** documenting the upstream lineage this fork derives
  from, including the MIT attribution for the meatro/OpenHaldex-S3 CAN analyzer /
  GVRET tooling and the ABangingDonk Gen1 origin. The README acknowledgements and
  a divergence note (what upstream items are deliberately not adopted, and why)
  were added to match.

### Fixed

- **Cancelling a Haldex learn no longer destroys the previous calibration.**
  Starting a learn wiped the table before the sweep began, so a cancel (or the
  speed interlock aborting mid-sweep) left the device with no table at all -
  silently reverting to the default CF formula and, because the BPK packing
  selector keys off table validity, potentially flipping Motor_11 from BPK back
  to V3 packing. The previous table is now snapshotted before the sweep and
  restored on cancel or abort; only a completed sweep replaces it.

- **Gen2/Gen5-0AY standalone Motor_5 rolling counter now actually rolls.** A
  copy-paste bug incremented Bremse_1's counter instead of Motor_5's, freezing
  the Motor_5 counter byte forever and pushing the Bremse_1 counter past its
  expected wrap band between frames, glitching that frame's continuity counter.
  Present in both the Gen2 and Gen5 (0AY) frame builders.

- **Gen41 heartbeat liveness now goes stale when the Haldex is unplugged.** The
  0x1CF/0x331 "alive" flags were set on frame arrival and never cleared, so the
  dashboard kept reporting the FDCM as alive after disconnection. Each flag now
  ages out off its own last-seen timestamp using the same 1 s health timeout as
  the rest of the CAN liveness logic.

- **Gen41 standalone 0x1C3 counter byte no longer clocked by dashboard
  housekeeping.** The 25 ms frame's D7 was fed from a main-loop debug counter
  whose rate depended on WiFi work, making the wire byte nondeterministic. It
  now uses a dedicated rolling counter stepped once per frame.

- **Drive mode no longer resets on reboot.** Changing the haldex generation in
  Settings wrote the generation number (1/2/4/41/50/51) into the stored drive
  mode, which is a separate 0-5 value. On the next boot that out-of-range value
  didn't match any mode and fell back to FWD, so the device forgot the mode you
  had selected. Setting the generation no longer touches the stored mode. The
  boot mapping from stored mode to runtime mode is now a host-tested
  `mode_from_last_mode()` seam with regression tests covering the generation
  values that used to corrupt it. Inherited from the upstream V8.00.2 import.

- **ESP_14 launch authority: full command now declares the full operating
  range.** The standalone Gen 5.0 CQ path fed the correction-factor-attenuated
  torque into `BR_Vorg_*_Max`, which is the operating-range ceiling, not a
  torque request - collapsing the declared range to ~60% and capping PWM below
  stock at full command. Range-max is now decoupled from the CF via a host-tested
  `esp14_range_max()` seam (byte-identical to the CAN-passthrough edit), so full
  command declares the full 0xFE range and the launch floor gains real headroom.

### In progress (not yet confirmed on-device)

- **Phone cellular-data while connected to the device.** When a phone joins the
  device's WiFi, its OS fires an internet-check probe (Android `generate_204`,
  Apple `hotspot-detect`, Windows NCSI, Firefox `canonical`). The intent is for
  the AP to answer those so the OS concludes "no internet, not a captive portal"
  and keeps its own 4G/5G alive. This build adds a catch-all DNS responder plus a
  bare-404 probe handler toward that, but on-device testing shows the phone still
  drops cellular - the fix is not yet working and the approach is under review.
  The `is_captive_probe()` probe set remains host-tested. Do not rely on this
  behaviour yet.

---

## v8.00.17 - 2026-09-17

### Added

- **Calibrate tab.** A new top-level tab (second in the nav, after Dashboard)
  that groups the per-car setup in the order it should be done: Generation,
  Learn Haldex, Lock calibration, and the Launch PWM floor. Each control has a
  short inline description plus a tappable (i) button that opens a plain-language
  explanation, aimed at users who plug the module in without reading a manual.
  These controls moved out of the Settings "Haldex Calibration" card; Settings
  keeps triggers, controller options, low-power, and updates.
- **Not-calibrated warning (soft gate).** When no learn table exists, the
  Dashboard shows a dismissible banner explaining that lock is running on an
  estimated factor and usually drives worse than Stock until a Learn is run, with
  a shortcut to the Calibrate tab. The Calibrate tab shows a matching
  calibrated/not-calibrated status chip. Nothing is disabled - competent users
  (restored table, bench, deliberate stock passthrough) are not blocked. Driven
  off the `tableValid` flag already returned by `/api/learn/status`; front-end
  only, no firmware change.
- **Launch PWM floor (experimental).** A tunable slider (0-100%, defaults to 0 =
  unchanged) that raises the ESP_14 `BR_Vorg_*_Min` bytes the Haldex sees while
  lock is commanded. Upstream pinned these `Min` bytes at 0, letting the Haldex
  settle to its own minimum clutch PWM; raising the floor forces it to hold
  higher under load. The floor is routed through the same lock-target gating as
  the `Max` bytes, so it collapses to 0 off-throttle, in FWD, and while coasting
  (no always-engaged effect), and is clamped strictly below `Max` so the Haldex
  keeps modulation headroom. Applied on both the CAN-passthrough and standalone
  frame paths.

### Changed

- **Fix Hunting toggle removed from the web UI.** The learn already forces the
  DBC-correct BPK Motor_11 packing for its own duration and afterward whenever a
  valid learn table is present, so the manual toggle was only ever needed for a
  bare 554K controller at partial lock with no learn table. The BPK packing path
  and the `fixHunting` persistence field are unchanged internally (EEPROM layout
  is stable); only the confusing manual control is gone.

### Fixed

- **Stuck-at-100% lock on partially-learned tables.** When more lock was
  requested than the learn sweep ever measured, the learn-table lookup returned
  a hardcoded correction factor of 100. That made the firmware command the full
  frame value (full `bpkCeilingNm`) for a lock target the car never actually
  learned - the stuck-at-100% field symptom on a light-load or interrupted
  learn. The lookup now clamps to the correction factor of the highest learned
  engagement (argmax), so it never extrapolates past learned data. An all-zero
  table safely yields zero. Added regression tests covering in-range targets,
  partial sweeps, plateau tables, and the degenerate all-zero case.

### Fixed

- **Loss of drive from a stalled CAN controller no longer needs a physical
  replug.** Both CAN receive tasks (chassis and Haldex) waited on the frame
  queue with an infinite timeout. If a controller stopped delivering while the
  module was awake - a bus-off event, or the TWAI power domain coming back
  stopped after a light-sleep cycle - the receive call never returned, so the
  existing recovery code never ran. The task parked on a dead controller, the
  Haldex lost its frame feed, and the module sat dead until power was pulled.
  The receives are now bounded (250 ms), and a stalled controller is detected
  and recovered: a stopped controller is restarted, a bus-off one is sent into
  recovery, and if the drive-critical chassis bus stays unrecoverable for ~3 s
  the module cleanly restarts to restore drive. A running-but-quiet bus (normal
  gaps between frames) is treated as healthy and never escalates.
- **Automatic light sleep disabled to stop the CAN domain being powered down
  mid-drive.** On the ESP32-C6 there is no armed GPIO wake source for automatic
  light sleep, and entering it power-gated the TWAI domain, which could come
  back stopped with nothing to wake it. Light sleep is now off and the TWAI
  power domain is held up at all times; the low-power feature still saves power
  by shutting down WiFi and the LED (and parking the transceivers in aggressive
  mode) while the CPU keeps running, so the receive task, frame counter and wake
  ISR stay live and the module can always recover on its own. CPU frequency
  scaling for idle savings is unchanged.
- **Control-path deadlock backstop.** The low-power supervisor task now feeds
  the hardware task watchdog on every iteration, so if the shared state mutex is
  ever lost and the control path deadlocks, the watchdog reboots the module
  instead of leaving it hung.

## v8.00.16 - 2026-07-18

First tagged release of this fork. Everything below is the delta over Forbes
Automotive's OpenHaldex-C6 V8.00.2 base, shipped as a single merged flashable
image (`openhaldex-c6-v8.00.16-merged.bin`).

### Security

- **Committed OTA password removed.** V8.00.2 carries a hardcoded `OTA_PASSWORD`
  literal in source and prints it to the serial log. This fork removes it. There
  is no compiled-in credential and no build step to set one: on first power-up the
  device redirects to a `/setup` page where you set your own WiFi AP password
  (WPA2, 8-63 characters), stored to NVS. It is rotatable later from the WiFi
  Access Point card on the Diagnostics tab (`POST /api/wifi`).
- **The WiFi AP password is the single auth boundary.** There is no per-endpoint
  HTTP login. The mode, settings, tune and learn endpoints, plus host-to-device
  CAN injection on the analyzer port, are reachable by anyone associated with the
  AP - the same transport model as V8.00.2. What changed is that the committed
  password is gone, so the AP itself is the gate: until you set a WPA2 password
  the AP stays open only to reach `/setup`, and while it is open the dashboard and
  every other route redirect to setup and analyzer-port CAN injection is refused
  outright. Once the password is set the AP restarts secured, and joining it is
  the boundary for the UI, the endpoints and OTA flashing alike. Passive analyzer
  sniffing is receive-only and transmits nothing to the bus.
- **HTTP body buffer allocation corrected.** The request body buffer was
  allocated with `new String()` but ESPAsyncWebServer frees `_tempObject` with
  `free()`, which is undefined behaviour on a mid-body abort. It is now a
  `malloc`-owned buffer matched to the `free()` call, with the sentinel restored
  so trailing chunks of a rejected body no-op.

### Firmware correctness

- **Stock mode no longer mirrors engagement back as the lock command.** The
  lock-target calculation returned the Haldex's own reported engagement as the
  commanded target for Stock mode (both the base mode and a force-mode trigger
  configured to Stock). Whenever that value was packed into transmitted frames
  (standalone always; inline while editing), engagement 100% commanded 100%,
  closing a positive feedback loop that latched the clutch at full lock until
  FWD was selected or the unit power-cycled. Stock now commands zero forced
  lock, and the inline gateway detects "effective mode is Stock" (base mode or
  forced value) and forwards chassis frames untouched - true passthrough
  instead of frame edits built from mirrored engagement. The brake/handbrake
  follow override is skipped under the same condition, so effective Stock is
  a genuine passthrough even with a follow override enabled.
- **Standalone CAN frames no longer transmit uninitialized flag bits.** Around
  40 frame builders declared the outgoing `twai_message_t` on the stack and set
  only the identifier, length and data, leaving the flags word (extended-ID,
  remote-request, single-shot, self-reception) as stack garbage. A stray RTR or
  extended-ID bit would silently corrupt the keep-alive frames the Haldex
  depends on. Every local frame is now zero-initialized at declaration.
- **Debug printf calls no longer compile into release builds.** The `DEBUG()`
  macros were gated with `#ifdef enableDebug`, but `enableDebug` is always
  defined (as 0 or 1), so the live `Serial.printf` variant was selected even in
  the release build - per-second status prints on a serial port that release
  never opens, with every format string baked into flash. The gate is now
  `#if enableDebug`, restoring the intended release behaviour.
- **UDS::sendRequest capacity bug fixed.** The function zeroed the in/out
  `responseLen` before it was used as the copy bound, collapsing every bound to
  zero so every `readDataByIdentifier` returned zero bytes. Capacity is now
  captured before it is zeroed, so the built-in ECU read returns real data.
- **Haldex fin/clutch temp raw words exposed for calibration.** The 16-bit temp
  DIDs (`0x2BE4` cooling fin, `0x2BF1` clutch) are decoded with a
  `(rawLE - 22767) / 100` scale disassembled from the upstream binary that has
  never been checked against a known temperature. The decoded reading still
  displays, and the raw 16-bit wire words are now also exposed in the `/api` JSON
  (`coolingFinTempRaw`, `clutchTempRaw`) so the true offset and scale can be
  solved against live VCDS values once captured. The current scale is left in
  place until real data replaces it - no second guess is stamped over it.
- **ESP_10 (0x116) E2E checksum DataID corrected.** The `ID_SEQ_116` array was
  all `0x05`, a verbatim copy of the EPB_01/0x104 table, so the live pass-through
  and standalone generator both produced a wrong checksum for the ESP_10 frame.
  The correct VW MQB E2E DataID `0xac` is now used. Bench validation against a
  real Gen5 unit is still pending.
- **CAN bus-off recovery automated.** In V8.00.2 the bus-health alert read only
  ran inside an `if (detailedDebugCAN)` block, used the legacy single-bus
  `twai_read_alerts`, and had no recovery path, so a bus-off event left the
  controller stopped until power-cycle. It is now an always-on dual-bus
  `twai_read_alerts_v2` per handle, `twai_start_v2` is called on the recovered
  bus, and per-bus failure state is tracked so a single-bus recovery never clears
  the latch while the other bus is still stopped.
- **Uploaded lock-table rows validated against the speed axis.** The tune-upload
  handler checked each lock-table row length against the throttle axis count when
  the row is indexed by the speed axis. Masked today because both are 7, but a
  malformed row would slip through if the grid dimensions ever diverged.
- **Received engagement percentage clamped instead of extrapolated.** The CAN
  parser scaled the raw Haldex engagement byte with Arduino `map()`, which
  extrapolates outside its input window. A raw byte below the low bound produced a
  negative percentage that wrapped when stored in the `uint8_t` engagement global
  (e.g. -1 became 255), and a byte above the high bound exceeded 100. The scaling
  now clamps into the window first, so every generation's decoded engagement stays
  0-100; in-window frames are byte-identical to before.
- **Speed-disengage gate corrected.** The passive-mode speed gate read
  `(under==0) || (speed<=under) || (speed>=above)`, which was always true because
  the upper bound defaults to 0 (so `speed>=0` always held) and which disengaged
  lock in the wrong band. Lock is now permitted only while the vehicle speed is at
  or above the lower cut AND at or below the upper cut, with either bound of 0
  disabling that side.
- **Learn-table over-request clamps to the highest learned engagement.** When a
  requested lock target exceeded every value in the learn table, the correction-
  factor search fell through with a factor of 0 and delivered zero lock exactly
  when maximum lock was wanted. It now clamps to the highest learned engagement
  instead.
- **Non-monotonic tune axes rejected on upload.** The expert-map interpolation
  assumes strictly-ascending speed and throttle axes; an out-of-order axis
  silently mis-interpolated. The tune-upload handler now rejects a tune whose
  speed or throttle axis is not strictly ascending.
- **No-learn-table fallback correction factor corrected.** Without a valid learn
  table the Gen5 fallback scaled the requested lock with `(target / 2) + 20`,
  which over-delivered (a 40% request produced a ~40% correction factor instead
  of 30%). The formula now matches its own comment and the Gen4.1 branch,
  `(target + 20) / 2`, so a device with no learn data tracks the request instead
  of running high. Devices with a valid learn table were never on this path.
- **Learn sampling hardened against duty-loop overshoot.** Near lock-up the
  Haldex ECU briefly commands full PWM (an audible pump oscillation above ~60%
  engagement), so a single engagement read at the end of a learn step could
  decode to a clean 100 and, written verbatim, poison the learn table. Each
  correction-factor step now samples engagement across a short window and takes a
  median with a monotonic clamp against the previous step, rejecting a lone spike
  or CAN dropout without changing total learn duration.
- **Web UI restored after a failed filesystem OTA.** Both filesystem update
  paths (the merged image and a direct littlefs.bin upload) unmount LittleFS
  before overwriting the partition, but every failure branch returned an HTTP
  error and left it unmounted, killing the web UI until a power cycle. Every
  failure path now attempts a remount (best effort - a partially-written
  partition may not mount, but the HTTP API and a retry upload keep working
  either way), and a failed littlefs.bin upload revokes its chunk
  authorization so trailing chunks stop writing to the partition. Concurrent
  uploads are rejected (409) while one is in progress, and a client that
  vanishes mid-transfer triggers a disconnect cleanup that aborts the open
  OTA handle, remounts the filesystem, and releases the in-progress flag -
  previously a torn upload left all of that latched until a power cycle.
- **UDS read endpoint validates the request CAN ID.** `/api/uds/read` rejected
  a malformed response ID but let a malformed request ID parse to 0 and
  transmit the UDS request on CAN ID 0x0. Both IDs are now validated.
- **CAN transmit failures are counted instead of ignored.** Every gateway-path
  transmit ignored its return value, so a send that failed at the call site
  (TX queue full, driver stopped) vanished without a trace. Sends now go
  through a wrapper that counts failures per bus and logs the first and every
  256th in debug builds; driver-level TX errors were already surfaced via bus
  alerts.

### Safety interlocks and fail-safes

- **Learn sweep speed interlock.** The learn sweep ramps the clutch to full
  lock over ~30 seconds and could previously be started (and would keep
  running) at any road speed. Starting is now refused above 5 km/h, and a
  running sweep aborts itself if the car moves off, without publishing the
  partial table. The web UI reports why.
- **Stale CAN inputs now fail safe.** Speed, throttle, the ESP/hazard
  force-mode flags, ABS validity and reported engagement were only ever
  overwritten by frame arrival, so on chassis or Haldex bus loss they latched
  their last value indefinitely - in standalone that meant synthesizing lock
  from stale data forever, including a stale force-mode flag holding a forced
  mode on. Once the existing 1-second CAN health timeout declares a bus dead,
  those inputs are zeroed; zero speed/throttle fails the lock-enable gates, so
  the commanded lock decays to open.
- **`/api/uds/read` no longer steals frames from the CAN gateway.** The
  diagnostic read helper called `twai_receive` directly from the web handler -
  a second consumer racing the gateway parse task for every bus-0 frame, with
  each frame it won consumed and never forwarded, while blocking the web
  server task for up to 2 seconds. Responses are now tapped (copied) out of
  the normal parse path into a dedicated queue, the gateway keeps every frame,
  concurrent reads are rejected, and the wait is bounded at 300 ms.
- **CAN driver queues resized from seconds of backlog to ~30 ms.** The TWAI
  queues were 2048 RX / 1024 TX per bus (~140 KB of heap) - deep enough that a
  stalled parse task would later replay several seconds of stale chassis
  frames to the Haldex instead of dropping them. Now 128 RX / 64 TX; real
  overruns surface through the existing RX_QUEUE_FULL alert monitoring.
- **Speed byte in the OpenHaldex CAN broadcast clamps instead of wrapping.**
  The 0x6B0 status broadcast truncated the 16-bit vehicle speed to its low
  byte, so 256 km/h read as 0 to any consumer (gauge, external display). It
  now clamps at 255.
- **Every API POST path now answers.** The mode handler never sent an HTTP
  response at all, and the settings/tune handlers returned silently on invalid
  input, leaving the client hanging until TCP timeout - visible as random UI
  freezes on a weak AP link. All paths now return explicit success or a 4xx
  with an error message, and the UI shows a toast instead of silently
  snapping the mode highlight back.

### Web UI safety and accessibility

- **Destructive actions confirm first.** Clear Learn Data (which destroys a
  calibration that takes a full sweep to rebuild, and sits directly under the
  Learn/Cancel buttons) and Restore Defaults (adjacent to Apply) both asked no
  questions; each now requires a confirmation, and Clear Learn Data is styled
  as a danger button.
- **Settings toggles are reachable by keyboard and screen reader.** The
  toggle checkboxes were `display:none`, removing every settings switch -
  including Disable Controller - from the tab order and the accessibility
  tree. They now use the visually-hidden pattern with a visible focus ring,
  and the touch target meets the 44px minimum.
- **Service worker never caches `/ota/`.** The updater polls `/ota/health` to
  detect the post-flash reboot; a cached response would report the module up
  while it was still flashing. `/ota/*` now always goes to the network, like
  `/api/*`.

### Concurrency and persistence

- **Shared control state guarded with a mutex.** Cross-task globals (drive state,
  lock target, and the tables the standalone generators read) were unguarded. A
  single non-recursive `stateMutex` is created before any task spawns and the
  read/write sites are guarded, so the CAN hot paths can't read a half-updated
  value.
- **Settings consolidated onto one NVS namespace.** `readEEP` called
  `pref.begin()` with a setting name as the namespace per call, so only the
  last-opened namespace persisted and first-run seeding never ran. It is
  consolidated onto a single `openhaldex` namespace with a first-run seeded
  sentinel and a one-time migration from the prior de-facto namespace.

### Changed

- **Lock response tuning re-united from %/s to milliseconds.** The attack and
  release sliders were percent-per-second, so a "5 second decay" was buried in an
  awkward unit (5 %/s) and fine control was impossible - near the fast end even a
  10 ms change needed thousands of %/s of slider resolution. They are now
  milliseconds for a full 0-100% travel, `0-1000 ms` in clean 10 ms steps, and
  `0 = instant` in each direction. Making release instant also removes a footgun:
  under the old unit a release rate of 0 meant "never releases" (clutch stuck
  locked), which is why release was floored at a nonzero rate; in milliseconds 0
  cleanly means "snap open." Persisted `%/s` settings on existing devices are
  migrated once to the equivalent time (old 120 %/s release default becomes
  833 ms) and re-saved under the new keys.
- **Dashboard layout consolidation.** The five tabs were 21 stacked single-topic
  cards; related controls are now grouped into 13, cutting vertical scrolling
  by roughly 40% with no signal removed. The Haldex state readout folds into the
  glance card footer; the Lock Response trace sits as its own card directly below
  the glance tiles so the temps/speed/throttle tiles stay top-of-screen on a
  phone; the three lock-disable cutoffs (under-speed, above-speed, min-throttle) become
  one "Lock Disable Conditions" card with a per-row icon and a live hint that
  warns when the two speed cutoffs overlap into a dead band; the CAN status,
  signals and brake/handbrake cards merge into one "CAN" card; the two WiFi
  cards into one "WiFi Access Point"; and the Settings tab folds the generation
  selector into the Learn card and the output toggles into "Inputs & Triggers".
  DOM ids are unchanged, so load/save and the API payloads are untouched.
- **Dashboard hero relabelled "Target duty" -> "Target lock".** The big hero
  number reads `lockTarget`, which the firmware derives from the drive mode (50:50
  requests 100, 60:40 requests 40, and so on) - it is the lock percentage the unit
  is requesting, not a coil duty cycle. The old "Target duty" label wrongly implied
  it was the solenoid PWM the Haldex module applies, which is a separate quantity
  the module chooses itself. The label now matches what the value actually is.
- **Dashboard poll rate no longer pinned to 1Hz.** The live poll used a fixed
  500ms `setInterval` with a one-in-flight guard; when a response landed just after
  a tick had already fired and bailed, the next tick was a full interval away,
  collapsing the effective rate from a nominal 2Hz to about 1Hz. The poll is now a
  self-scheduling loop that fires the next request as soon as the previous one
  settles (150ms floor), so the update rate tracks the device's real response
  latency instead of being quantised to a fixed tick. A generation token stops the
  loop while the page is hidden so backgrounding can't leave two loops running.

### Fixed

- **Haldex temperatures could read a fake 0 before the first sample.** The UDS
  clutch and cooling-fin temperatures (decoded and raw) are zero until the module
  first answers, and were published to `/api` as `0` - indistinguishable from a
  real 0 degC reading, which corrupted the raw-byte capture used to solve the
  temperature scale. Each field now publishes as `null` until its DID has been
  decoded at least once in the session, and reverts to `null` when the session
  ends.
- **A learned lock table could be applied to the wrong CAN frame.** A learning run
  always runs under the DBC-correct BPK packing, so the table it builds is calibrated
  against BPK frames. But when driving with Fix Hunting off the firmware sent the
  legacy V3 frame while still applying that BPK-measured table - a mismatch that
  made lock behave differently than it did during the Learn (worst case, stuck at
  full lock). The frame selector now stays on BPK whenever a valid learn table
  exists, regardless of the Fix Hunting switch, so what you calibrated is what you
  drive. Users who have never done a learning run are unaffected and keep the V3 default.
  The standalone CAN path now shares the same selector, so it can no longer drift
  from the passthrough path.
- **Map slots read "Empty slot" on Load, and you couldn't choose which slot to
  save into.** Two problems in the on-device tune slots. First, the saved-tune
  list and the Load action decided "is this slot used?" with two different NVS
  calls - the list checked the stored blob's reported length, Load actually read
  the blob back - and those two calls can disagree, so a slot that loads fine
  could still be listed as empty (and vice versa). The list now reads the blob
  the exact same way Load does, so the two can never disagree. Second, empty
  slots were greyed out in the dropdown, so there was no way to pick a specific
  slot to save into - "Save As" just took the first free one. Empty slots are now
  selectable and each option shows its slot number, so you can save straight to a
  chosen slot (and re-save reclaims any slot that had been left unreadable).
- **Accidental toggle/slider changes while scrolling.** On the phone a finger that
  landed on a slider while flicking the page would drag the value, and a scroll
  that started or ended on a toggle would flip the switch - so Standalone, Disable
  Controller and the sliders changed by accident. Sliders now let a vertical scroll
  pass straight through (only a deliberate sideways drag moves them), and a toggle
  ignores a "tap" whose finger actually moved (a scroll, not a press). Sliders also
  no longer jump their value when you tap the bar - the value only changes when you
  grab the thumb and drag it, so a stray press on the track can't slam a setting to
  wherever your finger landed.
- **Disable Controller, Standalone and Analyzer now confirm before switching on.**
  These three take the unit out of active control, so switching one into its
  disruptive state now asks first - a stray tap can't silently disable the
  controller, go standalone, or enter analyzer mode. Turning them back off is
  unchanged.
- **Drive-mode selection no longer snaps back to the old mode.** The dashboard
  re-applies the device's reported mode every poll so external changes show up, but
  a poll already in flight when you picked a new mode would report the old mode and
  revert the highlight. The UI now holds your selection until the device confirms
  the new mode (or a short timeout), so the pick sticks.
- **Expert multi-select: first tap after a long-press is no longer eaten.** The
  long-press that enters multi-select armed a "swallow the next click" guard to
  absorb the ghost click a touch normally trails. But a long hold makes the
  browser fire `contextmenu` instead of `click`, so the ghost never came and the
  guard stayed armed, eating the user's next deliberate cell tap (the reported
  "first box doesn't highlight" bug). The guard is now armed with a short expiry,
  so a tap arriving after the ghost window registers normally.

### Added

- **Live diagnostics step aside for an external scan tool.** When a real scanner
  (VCDS, ODIS or a generic OBD tool) starts addressing the chassis bus, the
  device auto-pauses its own MQB UDS polling so the two don't fight over the
  diagnostic session, then resumes on its own once the tool goes quiet for four
  seconds. Detection watches Bus 0 for the reserved ISO/VAG tester request ids
  (`0x7DF` OBD functional, and the `0x700`-`0x71F` physical-tester range); our
  own polling transmits on Bus 1, so any of those seen inbound is a foreign tool.
  The live-data API exposes `diagToolActive` so the UI can show why the readout
  paused. The match and the timeout window are host-tested pure predicates
  (`is_external_diag_request_id`, `external_diag_active`). Forbes independently
  added the same coexistence in upstream V8.00.3; this is the equivalent on the
  V8.00.2 base with the decision logic pinned by the native test suite.

- **Software Update card with single-file OTA.** The Settings tab now has a
  Software Update section: current firmware version/build/slot, the live
  safe-state gate with its blocking reason, and one upload-with-progress slot.
  It takes the release's single merged image - the same file used for USB
  flashing - and updates firmware and web UI in one upload, so an end user
  handles exactly one file. `POST /ota/update` classifies the upload from its
  first bytes: a merged image is split by flash offset (app segment to the
  spare OTA slot, filesystem segment to the LittleFS partition; the
  bootloader, partition table and NVS regions are skipped, so settings and the
  learn table survive), while a bare `firmware.bin` or `littlefs.bin` still
  works for partial updates (`POST /ota/updatefs` remains as the explicit
  filesystem endpoint). The firmware path keeps the dual-slot OTA semantics
  (write to spare slot, reboot, auto-rollback on failed safety checks), and
  everything sits behind the same safe-state gate. Wrong-file guards check
  real image magics: filesystem writes require the littlefs superblock magic,
  and an ESP image too big for the app slot but too short to be a merged image
  is rejected as truncated. The classification and merged-image chunk routing
  live in a host-tested pure header (`OpenHaldexC6_OTARoute.h`). Previously
  the OTA endpoints existed but nothing in the UI linked to them - updating
  meant knowing to type `/update` into the address bar, and the web UI itself
  could not be updated over the air at all.

- **Installable PWA.** The web UI can be added to a phone home screen and
  launched full-screen with one tap: web app manifest, generated icon set
  (including maskable and Apple touch icons), and a service worker. The service
  worker never caches `/api/*` or POSTs - live telemetry and control always hit
  the device - and serves the HTML/CSS/JS shell network-first so a UI update is
  picked up the moment the module is reachable, with the cached shell as a
  fallback when it briefly is not. iOS Safari gets full standalone from the
  Apple meta tags alone; Android Chrome may open as a browser tab over plain
  http (secure-context rule), where Samsung Internet is more lenient.

- **Full-screen toggle in the header.** One tap hides the browser chrome using
  the Fullscreen API, which - unlike PWA install - works over plain http, so an
  unmodified phone gets the full-screen dashboard without any flags or install
  step. The button hides itself where the API doesn't exist (iPhone Safari).
  The manifest also declares `display_override: fullscreen`, so when the app
  is installed from a secure context, supported browsers open it full-screen.

- **Plain-English help across the tuning UI.** The drive-mode drawer now
  describes what each mode actually does (Stock passes the factory engagement
  through, FWD holds the rear open, 50:50/60:40/75:25 hold progressively lighter
  fixed lock targets, Expert follows the throttle/speed map) instead of showing
  bare labels. Added inline hints to the previously unexplained controls: Haldex
  Generation, the brake/handbrake follow/invert outputs, and the Controller and
  Connectivity toggles (Controller Disabled, Standalone Mode, Use CAN if
  Available, Broadcast over CAN). Copy only - no behaviour change.

- **Per-corner slip and drive-mode over the diagnostic channel.** OpenHaldex now
  answers three supplier-specific UDS DIDs on the Haldex address (0x70F request ->
  0x779 response), the same channel that already carries clutch temps/PWM, because
  the car's gateway does not forward the passive 0x6B0/0x6A0 broadcasts to the OBD
  port. `0xFDA0` (lock) returns commanded lock %, applied engagement, and the live
  drive mode. `0xFDA1` (slip) returns geometry-compensated per-corner slip - each
  wheel's actual speed against the speed Ackermann geometry predicts for its turn
  radius at the current steering angle, so a straight launch and a mid-corner
  break-loose both read true slip rather than steering geometry, in [FL,FR,RL,RR]
  order. `0xFDA2` (mode) is a WriteDataByIdentifier target: a one-byte mode write
  sets `state.mode` (validated, mutex-guarded) and replies positive, so a UDS
  tester such as the Rokketek gauge can set the drive mode and confirm it by
  reading `0xFDA0` back. The four corner-slip values are also exposed as
  `cornerSlip` on the web dashboard JSON. TT Mk3 geometry constants are
  compile-time and flagged for on-car calibration. Not present in V8.00.2.

- **Learn Haldex calibration chart.** When a learned calibration table exists the
  Learn section now plots it as a curve - commanded correction factor on X,
  measured Haldex engagement on Y - against a dashed 1:1 reference, so where the
  Haldex over- or under-responds reads at a glance. It renders on page load and
  after a learn completes, and clears when the table is cleared. Render-only from
  the table `/api/learn/status` already returns; no firmware change, no extra
  device load.

- **Steering-gain reduction (off by default).** Scales the lock target down as
  steering angle increases, so the rear axle is not fighting the front through
  tight corners and car parks. The angle is decoded from the MQB LWI_01 (0x086)
  frame; gain stays 100% up to a configurable start angle, ramps linearly to a
  configurable minimum by the full angle, and the reduction is bypassed whenever
  the steering signal is stale or flagged degraded (fails toward stock
  behaviour). Toggle and sliders live in the web UI; the live signed angle and
  applied gain show on the Diagnostics page so the decode can be verified on the
  car before enabling. Not present in V8.00.2.
- **Lock engage rate, and the dead rate-limit settings wired up.** V8.00.2
  rate-limits only the release direction, and its lock-release rate slider and
  enable toggle were POSTed by the web UI but never read by `/api/settings`, so
  they did nothing. This fork accepts and persists both, adds a lock-engage rate
  so rising transitions can be slewed too (0 keeps the instant default), and
  shares one step function between both directions.
- **Web UI restyle and mobile pass.** A dark dashboard theme, a semi-circular
  engagement arc gauge with a target tick, polling that pauses while the page is
  hidden, and general touch and reduced-motion polish. Client-side hardening:
  overlapping status polls are guarded and time-bounded, missing DOM nodes are
  handled, and failed settings fetches no longer throw.
- **Expert tune-map curve view.** The Expert editor now draws the lock surface
  as a line chart below the grid, so the 7x7 table of numbers reads as curves
  while you tune. Two views toggle between lock-vs-speed (one line per throttle
  band) and lock-vs-throttle (one line per speed band), with a colour ramp and
  legend for the bands. It is read-only and redraws as cells or axis values
  change; it does not alter what is written to the Haldex.
- **Connection-status badge.** The header now shows a live/reconnecting/offline
  badge driven by the dashboard poll. A dropped access-point link used to leave
  the last gauge values frozen on screen looking current; the badge flips to
  "Reconnecting…" after the first missed poll and "Offline" after three, so
  stale numbers can't be mistaken for live data while driving. Recovers to
  "Live" on the next good poll.
- **Live lock-response trace.** The dashboard now plots a rolling 15-second
  strip chart of lock target vs actual engagement beneath the gauge. Where the
  gauge shows the instant pair, the trace shows how the actual chased the target
  over time, so coupling lag and the effect of the attack/release rate limits
  read at a glance while tuning. It is fed from the same dashboard poll (no extra
  device load), and the trace clears on a dropped link so a reconnect never
  bridges the outage. Target and actual drop out independently: the dashed target
  line breaks only where no CAN target is present, and a missing engagement
  reading breaks the actual line rather than plotting a phantom drop to zero or
  taking the target's line down with it.

- **On-device saved tune slots.** Five named map slots now persist in device
  NVS with list/get/save/delete endpoints, so a tune saved from one phone is
  visible from any phone. The slot library uses its own NVS namespace and never
  touches the settings handle. Replaces the earlier phone-side file
  export/import.
- **Gen5 BPK lock calibration is now a per-car setting.** The "Fix Hunting"
  (BPK) Motor_11 packing baked in one fixed calibration value for the 100%-lock
  point, so a car whose Haldex under- or over-responded to the commanded lock
  had no way to correct it. It is now an adjustable "Lock calibration" on the
  Settings page (range 100-500, default unchanged so existing behaviour is
  preserved). It is a calibration constant, not a strength dial: there is one
  correct value per car, found by running a Learn and adjusting until commanded
  lock matches delivered lock (the Sent vs Returned trace on the 1:1 diagonal) -
  higher does not lock harder. The underlying packing math was widened past its
  old 8-bit cap to the full MQB signal range, and the standalone and
  CAN-passthrough copies of the Motor_11 packing were de-duplicated into one
  host-tested function so the two paths can no longer drift.
- **Dashboard wakes for a USB host on the bench.** A USB host on the USB
  Serial/JTAG port now keeps the AP up and wakes a sleeping device, so the
  dashboard is reachable on the bench without a CAN source. Vehicle-powered
  operation has no USB host, so in-car low-power behaviour is unchanged.

### Build and test

- **Host-runnable native test suite added.** A PlatformIO `[env:native]`
  environment with Unity characterization tests pins the pure-function core:
  CRC8/AUTOSAR checksum, expert-map interpolation, lock-response rate limiting,
  steering-gain reduction, and the low-power fps-threshold wake decision. The
  wake decision was extracted into a pure `lpCanActive` seam so the firmware and
  the native test share one source of truth. Run with `pio test -e native`.
- **Release build profile added.** A separate `esp32c6-release` environment that
  forces all debug output off.
- **Board definition added.** The `esp32-c6-mini-1-n4` board file the build
  requires, which the upstream source drop did not include.
- **CI now packages a flashable binary.** The `firmware-build` job builds the
  LittleFS web-UI image and merges the bootloader, partition table, firmware and
  filesystem into one `firmware-merged.bin` (flash at `0x0`) via
  `scripts/merge_firmware.py`, which resolves the flash offsets from the built
  partition table. Every run uploads the individual binaries plus the merged
  image and `SHA256SUMS.txt` as artifacts. A tag push (`v*`) publishes a merged
  flash-from-scratch image and per-partition binaries to a GitHub Release. The
  release job holds `contents: write` scoped to itself; the rest of CI stays
  read-only.

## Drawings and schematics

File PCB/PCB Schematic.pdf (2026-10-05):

Schematic | Haldex C6 V1.0 | Create at | 2025-11-05
Update at | 2025-11-09
Board | Haldex C6 V1.0 | Page | Power +USB
Drawn | | OpenHaldexC6-V1.01

# Reviewed

Version | Size | Page 1 Total 3
V1.0 | A4 | EasyEDA.com

VCC

GND
GND

ADJ(GND)

1 VOUT(TAB) 2
VIN 3
TAB 4

U4

AMS1117-3.3

Switching Regulator 6.5V to 24V ->5V

C6
22uF

C5
22uF

FB 8

SS 7

BST 6
SW 5
GND 4

VIN 3
EN 2
RT 1

U2

TPS62933DRLR

RT

SS

BST

SW
FB

F1
06H1100D VBAT_UF

VBAT

R3280pF@¹MHz
D3
SMF24CA

U5
SMF24A

L1
3.3uH

EN_TPS

Note:EN has internal pull-up Float=Enable
Low=Disable

C10
22uF

+3.3V

+5V

Input protection | Buck | LDO

GND

1

VO- 2

VI+ 3

U3

CH213K

BUCK_OUT

+5V

C8
47uF

C9
47uF

C11
47uF

20K on RT= 1.09MHz switching freq

PWR Indicator

C12
33nF

R2
52.3k

R4
20k

R5
10k

C1

100nF

C7
100nF

R1
1k

GND

USB_D+
USB_D-

CC1

CC2

GND 1
VBUS 2
SBU2 3
CC1 4
DN2 5
DP1 6
DN1 7
DP2 8
SBU1 9
CC2 10
VBUS 11
GND 12 SHELL 13

SHELL 14

USB1

TYPE-C 16PIN 2MD(073)

GND

VBUS

USB_D+

USB_D- | ESP_USB_D- ESP_USB_D+

USB Conenctor

USB Protection
I/O1 1
GND 2
I/O2 3

I/O2 4

VBUS 5

I/O1 6

D10

USBLC6-2SC6

GND

1

VO- 2

VI+ 3

U6 CH213K

VBUS

C14
22uF

C13
22uF

GND

VBUS

+5V

Q1
2N7002

GND

EN_TPS

TPS Disable on USB Power

BackFeed Protection

USB

Note: Remove 10K resistor (R9) if you dont want the USB plugging in to disable the VCC Power In

R10
5.1k
R12
5.1k

R9
10k

D1

SS3P3-M3/84A

Note: CH213K is reverse voltage protection diode with over-curent protection with 1A limit
As an added bonus its low Ron(around 160m ) creates a RC low pass filter
~ 100kHz due to MLCC capacity derating from voltage

As long as at 5V line stays above 4.5V all will work well

WARNING: DO NOT use LONG USB CABLES to power the device.

They use thin,long wires and will create a substatial voltage drop making the 5V supply line TOO LOW.

## If you MUST use a long USB cable remove R9 and power the module from 12V source via the PWR in and GND pins on the connector

The lower limit on the 5V line is 4.5V due to the LDO dropout voltage and the CAN tranciver

## both needing 4.5V minimum to work correctly Measure between the 5V and GND test points on the board to verify voltage You can measure USB voltage before protection diode on VBUS test point

LED2

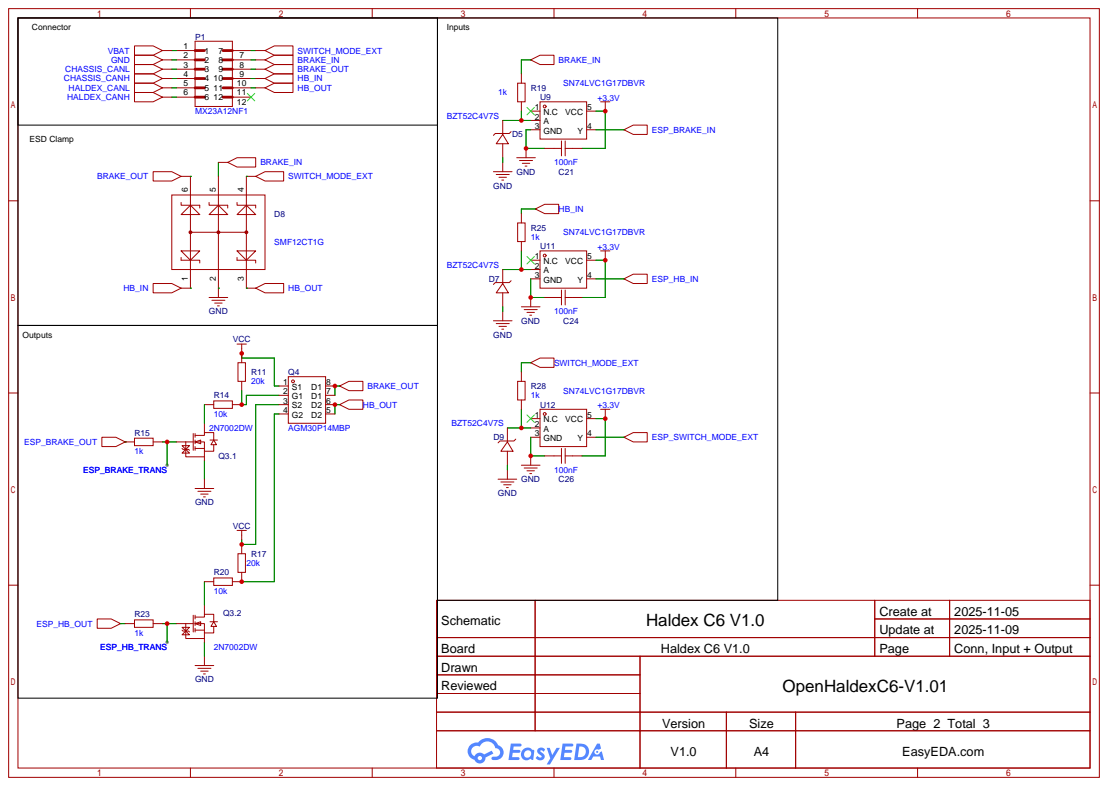
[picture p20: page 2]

Schematic | Haldex C6 V1.0 | Create at | 2025-11-05

Update at | 2025-11-09

Board | Haldex C6 V1.0 | Page | Conn, Input + Output
Drawn | | OpenHaldexC6-V1.01
Reviewed

IO21 27 IO22 28 IO23 29 RXD0 30 TXD0 31 NC 32 NC 33 NC 34 NC 35 GND 36 GND 37 GND 38 GND 39 GND 40 GND 41 GND 42 GND 43 GND 44 GND 45 GND 46 GND 47 GND 48 GND 49 GND 50 GND 51 GND 52 GND 53

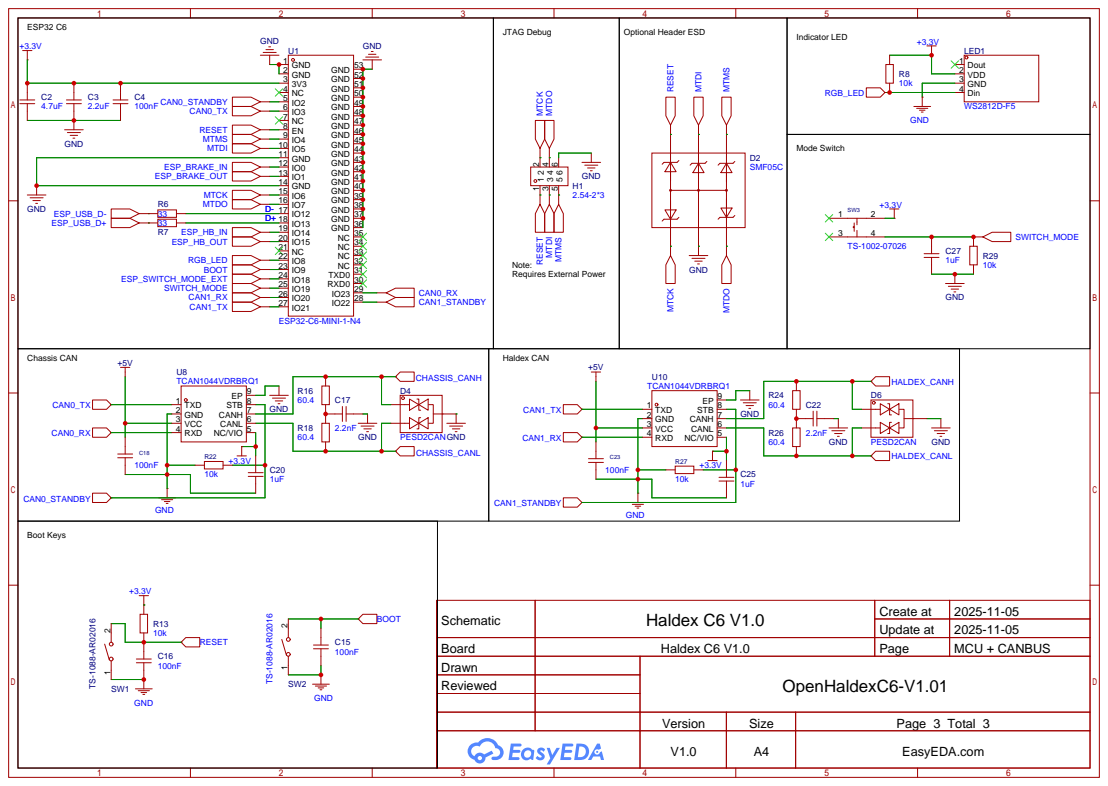
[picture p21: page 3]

Schematic | Haldex C6 V1.0 | Create at | 2025-11-05

Update at | 2025-11-05

Board | Haldex C6 V1.0 | Page | MCU + CANBUS
Drawn | | OpenHaldexC6-V1.01
Reviewed

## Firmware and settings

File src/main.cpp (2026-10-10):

/*
OpenHaldex-C6 - Forbes Automotive
Haldex Controller for Gen1, Gen2, Gen4 and Gen5 Haldex Controllers
Version: 8.00.5
*/

#include <OpenHaldexC6_defs.h>
#include <OpenHaldexC6_can.h>
#include <OpenHaldexC6_EEP.h>
#include <OpenHaldexC6_IO.h>
#include <OpenHaldexC6_OTA.h>
#include <OpenHaldexC6_WiFi.h>
#include <OpenHaldexC6_Analyzer.h>
#include <OpenHaldexC6_API.h>
#include <OpenHaldexC6_ESPNow.h> // live state to can2gauge (and other displays) over ESP-NOW
#include <OpenHaldexC6_BLE.h>
#include <ESPmDNS.h> // for mDNS responder to allow openhaldex.local access to the web UI without needing to know the IP address
#include "esp_pm.h"  // for power management when CAN sleep enabled
#include "esp_heap_caps.h"

#if debugMemory
// Heap and per-task stack headroom, to size task stacks from evidence. On the
// C6, IRAM code, static RAM, task stacks, WiFi and BLE all come out of the same
// 512 KB SRAM - with too little left, BLE fails to init and the web server
// truncates pages. Stack "free" = high-water mark: the least unused stack that
// task has ever had (bytes on ESP-IDF).
static void printMemoryReport()
{
  DEBUG("MEM: heap free %u, min ever %u, largest block %u",
        (unsigned)heap_caps_get_free_size(MALLOC_CAP_INTERNAL),
        (unsigned)heap_caps_get_minimum_free_size(MALLOC_CAP_INTERNAL),
        (unsigned)heap_caps_get_largest_free_block(MALLOC_CAP_INTERNAL));
  twai_status_info_t s0 = {}, s1 = {};
  twai_get_status_info_v2(twai_bus_0, &s0);
  twai_get_status_info_v2(twai_bus_1, &s1);
  DEBUG("MEM: CAN rx missed/overrun chassis %lu/%lu, haldex %lu/%lu",
        s0.rx_missed_count, s0.rx_overrun_count, s1.rx_missed_count, s1.rx_overrun_count);
  const UBaseType_t n = uxTaskGetNumberOfTasks();
  TaskStatus_t *ts = static_cast<TaskStatus_t *>(malloc(n * sizeof(TaskStatus_t)));
  if (ts == nullptr)
  {
    DEBUG("MEM: no heap for the task list");
    return;
  }
  const UBaseType_t got = uxTaskGetSystemState(ts, n, nullptr);
  for (UBaseType_t i = 0; i < got; i++)
  {
    DEBUG("MEM:   %-20s stack free %5u", ts[i].pcTaskName, (unsigned)ts[i].usStackHighWaterMark);
  }
  free(ts);
}
#endif

void setup()
{
#if enableDebug || detailedDebug || detailedDebugCAN || detailedDebugWiFi || detailedDebugEEP || detailedDebugIO
  Serial.begin(500000);      // start serial at a high baud rate for debugging
  Serial.setTxTimeoutMs(10); // set a small timeout for Serial writes to prevent blocking if the Serial Monitor is not open
  // native USB-CDC: give the host up to 3s to attach so early boot logs (LittleFS/WiFi/mDNS) aren't lost before it connects
  unsigned long serialWaitStart = millis();
  while (!Serial && millis() - serialWaitStart < 3000)
  {
    delay(10);
  }
  delay(250);                          // small grace period after attach before the first message is sent
  DEBUG("OpenHaldex-C6 Launching..."); // debug message to indicate startup
#endif

  readEEP();        // read previously stored settings in EEPROM
  setupIO();        // setup IO
  setupCAN();       // bring CAN online
  setupButtons();   // setup mode & external mode buttons
  setupTasks();     // setup tasks
  setupWiFi();      // setup WiFi
  setupWebServer(); // setup WebServer
  setupAPI();       // setup API handling for WebServer
  setupOTA();       // setup Over-the-Air Updates
  setupESPNow();    // gauges over ESP-NOW (follows the AP: started / stopped with it)
  setupBLE();       // setup BLE link to the DashCAN app (stack comes up from its own task)

  // Power management: when CAN sleep is enabled, scale CPU frequency down
  if (canSleepEnabled)
  {
    esp_pm_config_t pm_cfg = {
        .max_freq_mhz = 160,
        // Aggressive: drop CPU lower limit to 10MHz (XTAL/N) for deeper idle.
        .min_freq_mhz = canSleepAggressive ? 10 : 40,
        // Automatic light sleep is DISABLED. On the C6 there is no armed GPIO
        // wake source for light sleep, and the TWAI domain power-gates on sleep
        // (setupCAN, sleep_allow_pd) and can come back stopped with nothing to
        // wake it - the module goes dead mid-drive until a physical replug.
        // The low-power feature still saves power by shutting down WiFi+LED (and
        // parking the transceivers in aggressive mode) while the CPU keeps
        // running, so the RX task, fps counter, and wake ISR stay live and the
        // box can always recover on its own. CPU frequency scaling (DFS) below
        // the max is still active for idle power savings.
        .light_sleep_enable = false,
    };
    esp_err_t pm_err = esp_pm_configure(&pm_cfg);
    if (pm_err != ESP_OK)
    {
      DEBUG("ESP Power Management Failed: %d (continuing without CPU frequency scaling)", (int)pm_err);
    }

    // Hold light sleep OFF while the module is awake. Automatic light sleep can
    // power down the TWAI power domain (setupCAN sets sleep_allow_pd); if the
    // restore ever fails the CAN controller comes back stopped and the Haldex
    // loses its frame feed - loss of drive. This lock blocks incidental light
    // sleep during live driving. The low-power state machine in updateTriggers
    // releases it only when it DELIBERATELY sleeps (5 min idle, no clients) and
    // re-acquires it on wake, so the shipped low-power feature is unchanged.
    esp_pm_lock_handle_t lk = nullptr;
    if (esp_pm_lock_create(ESP_PM_NO_LIGHT_SLEEP, 0, "can_live", &lk) == ESP_OK)
    {
      pmNoLightSleepLock = (void *)lk;
      esp_pm_lock_acquire(lk); // awake at boot
    }
    else
    {
      DEBUG("Failed to create PM no-light-sleep lock (CAN may sleep mid-drive)");
    }
  }

  if (needsFirmwareConfirmation())
  {
    DEBUG("[OTA SAFETY] New firmware detected - confirmation deferred to otaRollbackTick()");
  }
}

void loop()
{
  vTaskDelay(pdMS_TO_TICKS(100)); // yield the Arduino loop task so other FreeRTOS tasks can run

  otaRollbackTick(); // confirm a freshly-installed OTA image once the device has proven itself

#if debugMemory
  {
    static uint32_t nextMemReport = 15000; // after WiFi, web server, ESP-NOW and BLE have all started
    if (millis() >= nextMemReport)
    {
      nextMemReport = millis() + 60000;
      printMemoryReport();
    }
  }
#endif

  { // temp counters for debugging, just left in because they can be useful for testing timing of various functions/tasks
    tempCounter++;
    if (tempCounter > 5)
    {
      tempCounter = 0;
      tempCounter1++;
    }

    if (tempCounter1 > 10)
    {
      tempCounter1 = 0;
      tempCounter2++;
    }

    if (tempCounter2 > 254)
    {
      tempCounter2 = 0;
    }
  }

  // Low-power mode: shut down WiFi AP when there has been no CAN traffic for 5+ minutes
  // and no devices are connected. WiFi restarts automatically when CAN traffic returns
  if (lowPowerMode && WiFi.getMode() != WIFI_OFF)
  {
#if detailedDebugWiFi
    DEBUG("Low Power: Disabling WiFi AP");
#endif
    espNowStop(); // before the radio goes
    WiFi.softAPdisconnect(true);
    WiFi.mode(WIFI_OFF);
  }

  if (rebootWiFi)
  {
#if detailedDebugWiFi
    DEBUG("Restarting WiFi...");
#endif

    // just here to show a visual indication of the WiFi reboot
    for (int i = 0; i <= 3; i++)
    {
      strip.setLedColorData(led_channel, ledBrightness, ledBrightness, ledBrightness);
      strip.show();
      vTaskDelay(pdMS_TO_TICKS(50));
      strip.setLedColorData(led_channel, 0, 0, 0);
      strip.show();
      vTaskDelay(pdMS_TO_TICKS(50));
    }

    espNowStop();                // the ESP-NOW task brings it back once the AP is up again
    WiFi.disconnect(true, true); // disconnect and erase AP settings to ensure a clean restart
    WiFi.mode(WIFI_OFF);         // turn off WiFi to reset the state

    startSoftAP(); // restart in AP mode (local-only DHCP, current SSID/password)
    MDNS.end();
    MDNS.begin("openhaldex"); // restart openhaldex.local
    MDNS.addService("http", "tcp", 80);

    rebootWiFi = false;
  }

  pollWifiSta(); // bridge mode: track the home-network connection (no-op when not configured)
}

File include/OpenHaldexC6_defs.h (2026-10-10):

#pragma once

// general ESP activities
#include <Arduino.h>
#include <stdio.h>
#include <stdlib.h>
#include "freertos/FreeRTOS.h"
#include "freertos/task.h"
#include "freertos/semphr.h"
#include "esp_err.h"
#include "esp_log.h"
#include "driver/twai.h"
#include "driver/gpio.h"

// for CAN IDs - to make code easier
#include <OpenHaldexC6_canID.h>
#include <OpenHaldexC6_ver.h>

#include <OpenHaldexC6_led.h>              // for RGB LED (single WS2812, replaces Freenove lib - see header)
#include <Preferences.h>                   // for eeprom/remember settings

#include <WiFi.h>    // included for WiFi pages
#include <ESPmDNS.h> // included for WiFi pages
#include <AsyncTCP.h>
#include <ESPAsyncWebServer.h>
#include "esp_ota_ops.h"
#include <ArduinoJson.h>

#include <LittleFS.h>

#include "esp_ota_ops.h"
#include "esp_app_format.h"
#include "esp_partition.h"
#include "esp_https_ota.h"
#include "esp_flash_partitions.h"
#include "esp_log.h"

#include "InterruptButton.h" // for mode button (internal & external)

// debug options
// Release builds (-D OPENHALDEX_RELEASE, [env:esp32c6-release]) force every
// debug flag OFF regardless of what the developer defaults below are set to.
#ifdef OPENHALDEX_RELEASE
#define enableDebug 0
#define detailedDebug 0
#define detailedDebugStack 0
#define detailedDebugRuntimeStats 0
#define detailedDebugCAN 0
#define detailedDebugWiFi 0
#define detailedDebugEEP 0
#define detailedDebugIO 0
#define detailedDebugArray 0
#define debugCANSleep 0
#define debugMemory 0
#else
#define enableDebug 0               // set to 1 to enable debug messages over Serial; set to 0 to disable
#define detailedDebug 0             // set to 1 to enable more detailed debug messages (only recommended when debugging specific issues, as it can be very verbose)
#define detailedDebugStack 0        // set to 1 to print stack traces on errors (only useful if enableDebug is also 1)
#define detailedDebugRuntimeStats 0 // set to 1 to print FreeRTOS runtime stats periodically (only useful if enableDebug is also 1)
#define detailedDebugCAN 0          // set to 1 to enable detailed CAN debug messages (only recommended when debugging CAN-related issues, as it can be very verbose)
#define detailedDebugWiFi 0         // set to 1 to enable detailed WiFi debug messages (only recommended when debugging WiFi-related issues, as it can be very verbose)
#define detailedDebugEEP 0          // set to 1 to enable detailed EEPROM debug messages (only recommended when debugging EEPROM-related issues, as it can be very verbose)
#define detailedDebugIO 0           // set to 1 to enable detailed IO debug messages (only recommended when debugging IO-related issues, as it can be very verbose)
#define detailedDebugArray 0        // set to 1 to enable detailed debug messages for arrays (like throttle/speed/lock curves) - only recommended when debugging issues related to those, as it can be very verbose
#define debugCANSleep 0             // set to 1 to skip the 5-min idle/60-s count and sleep after ~2 s with no clients
#define debugMemory 1               // set to 1 to print heap + every task's unused stack 15 s after boot, then every 60 s
#endif

// Learn-sweep speed interlock: the sweep ramps the clutch to full lock over
// ~30 s, which is only safe with the car stationary. Starting is refused and a
// running sweep aborts above this speed (km/h). Standalone benches with no
// chassis CAN read speed 0 and are unaffected.
#define learnMaxSpeed 5

// refresh rates
#define eepRefresh 2000           // EEPROM save in ms
#define broadcastRefresh 200      // broadcast data over CAN refresh rate in ms
#define serialMonitorRefresh 1000 // Serial Monitor refresh rate in ms
#define updateTriggersRefresh 500 // change IO refresh rate in ms

// debugging macros. Must be #if, not #ifdef: enableDebug is ALWAYS defined
// (as 0 or 1) by the blocks above, so #ifdef selected the live Serial.printf
// variant even in release builds.
#if enableDebug
#define DEBUG(x, ...) Serial.printf(x "\n", ##__VA_ARGS__)
#define DEBUG_(x, ...) Serial.printf(x, ##__VA_ARGS__)
#else
#define DEBUG(x, ...)
#define DEBUG_(x, ...)
#endif

// helpers to format a number as a binary string for printf
#define BYTE_TO_BINARY_PATTERN "%c%c%c%c%c%c%c%c"
#define BYTE_TO_BINARY(byte)       \
  ((byte) & 0x80 ? '1' : '0'),     \
      ((byte) & 0x40 ? '1' : '0'), \
      ((byte) & 0x20 ? '1' : '0'), \
      ((byte) & 0x10 ? '1' : '0'), \
      ((byte) & 0x08 ? '1' : '0'), \
      ((byte) & 0x04 ? '1' : '0'), \
      ((byte) & 0x02 ? '1' : '0'), \
      ((byte) & 0x01 ? '1' : '0')

// GPIO
#define CAN0_RS 2  // can_0 slope control
#define CAN0_RX 23 // can_0 rx
#define CAN0_TX 3  // can_0 tx
#define CAN1_RS 22 // can_1 slope control
#define CAN1_RX 20 // can_1 tx
#define CAN1_TX 21 // can_1 rx
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

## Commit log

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2026-07-03 Fix UDS::sendRequest discarding every response
    responseLen is an in/out parameter: it carries the caller's buffer
    capacity on entry and the received length on return. The response
    collection path zeroed it before the single-frame, first-frame and
    consecutive-frame copies, so every copy was bounded by 0 and callers
    always got an empty response (readDataByIdentifier could never return
    data).
    Capture the entry capacity into a local const straight after the
    argument guard and use it for all three copy bounds. No protocol or
    frame changes.
    [OpenHaldexC6_UDS.cpp]
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2026-07-03 Remove the committed OTA password and fail closed when unprovisioned
    The firmware shipped with #define OTA_PASSWORD haldex (defined twice)
    and printed it to the serial console on boot, so every device shared one
    publicly known flashing credential.
    Replace the literal with runtime resolution: an NVS-stored password
    (otaCred/otaPass) wins over an optional build-time value injected via
    -D OPENHALDEX_OTA_PASSWORD, and when neither is set every flash path
    returns 503 instead of accepting a default. A first-run /setup page sets
    the password on a blank device (and closes once one is stored), and an
    authenticated POST /ota/credential changes it without reflashing.
    The upload handler now runs the a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
    [OpenHaldexC6_OTA.cpp]
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2026-07-03 Store settings in one NVS namespace and fix dead first-run seeding
    readEEP opened Preferences once per setting NAME (~28 pref.begin calls),
    but each begin() switches the handle's namespace, so only the last call
    won and every key silently lived in one arbitrary namespace. First-run
    detection then read "haldexGeneration", a key nothing ever writes, so
    the seed-defaults branch was unreachable and a blank device booted on
    whatever the getters' inline defaults happened to be.
    Store everything under a single "openhaldex" namespace with an explicit
    "seeded" sentinel. On boot readEEP either loads (seeded), migrates (a
    previous install's data found in the old de-facto namespace - "udsMQBEn"
    for rec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
    [OpenHaldexC6_EEP.cpp]
2026-07-03 Make CAN bus-failure detection always-on and add a recovery path
    Bus-health detection only ran inside if(detailedDebugCAN), a debug flag
    that ships off, and it used the legacy single-bus twai_read_alerts,
    which targets the wrong handle in this dual-bus v2 install. On a real
    fault (bus-off, error-passive, TX failure) isBusFailure never latched,
    nothing initiated recovery, and once set the flag could never clear
    because no code ever reset it.
    Read alerts from both buses every monitor pass with the v2 per-handle
    API. A failure latches per bus; while either latch is set the IO task
    keeps issuing twai_initiate_recovery_v2 (those calls already existed
    but could never fire). When TWAI_ALERT_BUS_RE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
    [OpenHaldexC6_can.cpp, OpenHaldexC6_defs.h, OpenHaldexC6_tasks.cpp]
2026-07-03 Correct the ESP_10/0x116 E2E checksum DataID table
    ID_SEQ_116 was a verbatim copy of EPB_01/0x104's all-0x05 table, so
    every ESP_10 frame OpenHaldex generates in standalone mode carries a
    CRC computed with the wrong VW MQB E2E DataID and a receiving Gen5
    Haldex should reject it. The correct all-0xac sequence was already in
    the file but mislabeled as ID_SEQ_110 for a 0x110 message that does not
    exist on this bus, with a checksum_110 wrapper nothing calls.
    Set ID_SEQ_116 to the 0xac DataID (matching gorgias.me's VW MQB E2E
    analysis and this firmware's own inline 0xac comments elsewhere) and
    delete the mislabeled duplicate table and its dead wrapper.
    Needs bench validation against a real Gen5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
    [OpenHaldexC6_defs.h, OpenHaldexC6_globals.cpp]
2026-07-03 Guard the shared control state with a mutex
    The mode, lock target, expert tune tables, learn table and disengage
    gates are written by the web callbacks, the mode buttons, the external
    CAN control frame and the learn task, and read concurrently by the
    priority-12 CAN hot path (parseCAN_chs -> getLockData) and the
    standalone frame generators. Nothing synchronized those accesses, so
    the Haldex could be fed a frame computed from a half-rewritten tune
    table, or see the learn-table valid flag set over a table still being
    scanned.
    Add one non-recursive FreeRTOS mutex, created at the top of setupTasks
    before any task spawns (halting if creation fails rather than running
    unsynchronized). getLockData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
    [OpenHaldexC6_Calculations.cpp, OpenHaldexC6_EEP.cpp, OpenHaldexC6_IO.cpp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]
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2026-07-03 Add a host-native characterization test suite for the pure core
    pio test -e native compiles OpenHaldexC6_globals.cpp and
    OpenHaldexC6_Calculations.cpp against a small stub-header layer
    (test/native/stubs) and pins their current outputs with Unity tests:
    - test_crc: crc8_autosar and calcChecksum wire bytes for the Motor/ESP
    DataID tables, including the corrected ESP_10/0x116 sequence.
    - test_calc: expert-map interpolation, per-mode lock targets, the
    force-mode trigger/priority block (both hazard-first and TC-first
    orderings), and get_lock_target_adjusted_value across the learn-table,
    learn-active and default-formula paths for Gen1 and Gen41.
    Golden values were recorded by running th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
    [test_calc.cpp, test_crc.cpp]
2026-07-03 Add a configurable lock engage rate and fix the dead rate-limit settings
    The lock-target limiter only rate-limited the release direction; lock-up
    was always instantaneous. Add lockEngageRatePerSec so rising transitions
    can be slewed the same way (0 keeps the instant behaviour and is the
    default), with the step logic in one testable function shared by both
    directions.
    The settings UI has always POSTed lockReleaseRatePerSec and
    lockReleaseEnabled on save, but /api/settings never read either key, so
    the slider and toggle silently did nothing. Accept both (release rate
    floored at 5 %/s so a client cannot configure a lock that can never
    release), report them from the settings GET, and persist th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
    [OpenHaldexC6_Calculations.cpp, OpenHaldexC6_EEP.cpp, OpenHaldexC6_defs.h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]
2026-07-03 Taper lock with steering angle to reduce driveline windup in tight corners
    Decode the MQB LWI_01 (0x086) steering-angle broadcast (13-bit magnitude
    in 0.1-degree units, sign, and the QBit quality flag) in parseCAN_chs and
    scale the lock target down as the wheel turns: gain stays 100% at or
    below a start angle, ramps linearly to a configurable minimum at a full
    angle, and is applied at the single choke point in getLockData so every
    generation's frame edits scale uniformly. Fail-safe by design - the
    feature ships disabled, and a stale or QBit-degraded angle leaves the
    gain at 100% (stock behaviour) rather than latching the last reduction.
    The four settings (enable, start angle, full angle, mi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
    [OpenHaldexC6_Calculations.cpp, OpenHaldexC6_EEP.cpp, OpenHaldexC6_can.cpp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]
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2026-07-04 Extract the CAN bus-health predicates and host-test them
    The always-on bus-failure and bus-recovery decisions were inline bitmask
    tests in the CAN alert loop. Pull them into can_alerts_indicate_failure and
    can_alerts_indicate_recovered in the pure-function unit, add the missing
    CAN_ALERTS_RECOVERED_MASK next to the existing alert masks, and call the
    predicates from the alert loop. A host-runnable test_bushealth suite now pins
    the failure/recovery verdicts and the mask composition (RX_DATA excluded from
    the failure set, BUS_RECOVERED enabled and in the recovered mask).
    [OpenHaldexC6_Calculations.cpp, OpenHaldexC6_defs.h, OpenHaldexC6_tasks.cpp]
2026-07-04 Extract the OTA credential policy and host-test it
    resolveOtaCredential picked the effective password inline and requireOtaAuth
    tested it for emptiness by hand. Pull the precedence rule (NVS over build
    default over empty) into select_ota_password and the configured check into
    ota_credential_configured, and route resolveOtaCredential, requireOtaAuth and
    isOtaCredentialProvisioned through them. analyzer_injection_allowed is added
    alongside for the analyzer gate that follows. A host-runnable test_auth suite
    now pins the fail-closed flash-authorization policy in one place.
    [OpenHaldexC6_Calculations.cpp, OpenHaldexC6_OTA.cpp]
2026-07-04 Gate host-to-device analyzer injection behind the OTA credential
    The analyzer TCP port accepted GVRET and SLCAN host-to-device transmit frames
    from any client and forwarded them straight onto CAN. Add a fail-closed
    injection gate: analyzerInjectionPermitted() resolves the credential in
    task-local storage once per TCP connection, and both transmit paths refuse
    (and count) an injected frame when no credential is provisioned. Passive
    sniffing and streaming are never gated. The decision composes the host-tested
    analyzer_injection_allowed predicate, pinned by a native test_analyzer_auth
    suite.
    [OpenHaldexC6_Analyzer.cpp, OpenHaldexC6_OTA.cpp]
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2026-07-04 Extract the UDS live-data decode and host-test it
    udsDecodeDID validated the ISO-TP single frame and applied the per-DID scaling
    inline. Pull the frame parse into uds_parse_sf_rdbi and the mixed-endian per-DID
    scaling into uds_scale_mqb_did (temperatures little-endian, clutch current and
    voltage big-endian), leaving udsDecodeDID to parse, scale and dispatch the value
    to the right live-data global. A host-runnable test_uds suite now pins the
    single-frame parse guards and every DID formula against hand-derived goldens.
    The parse also rejects a frame shorter than its own declared length, which the
    inline version did not check.
    [OpenHaldexC6_Calculations.cpp, OpenHaldexC6_UDS.cpp]
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2026-07-04 Re-evaluate the analyzer injection gate per session and round the PWM store
    The host-to-device injection flag was only set when a WiFi analyzer client
    connected. A serial GVRET session never re-evaluated it, so it inherited the
    previous WiFi session's decision - a permitted WiFi client could leave serial
    injection enabled without a fresh credential check. Evaluate the gate at
    serial start too, and clear it whenever neither analyzer mode is active so it
    always fails closed until a session re-checks the credential.
    Also round and clamp the clutch-PWM value before storing it: udsClutchPWM is a
    uint8_t and the decode dispatcher hands it a float, which would narrow
    silently. The value scales to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
    [OpenHaldexC6_Analyzer.cpp, OpenHaldexC6_UDS.cpp]
2026-07-04 Remove the build-time OTA password fallback
    The OTA credential could be supplied at compile time via a
    -D OPENHALDEX_OTA_PASSWORD build flag, which select_ota_password() used
    as a fallback when no NVS value was stored. That left a second, hidden
    way to bake a credential into a build and contradicted the documented
    model: open AP by default, password set once at runtime via /setup.
    Drop the build-time source entirely. select_ota_password() now takes
    only the NVS value and normalises an empty or absent value to the ""
    fail-closed sentinel, so the flash and analyzer-injection gates still
    refuse (HTTP 503) until a runtime credential exists. The OTA and
    analyzer credential-policy tests are updat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
    [OpenHaldexC6_Calculations.cpp, OpenHaldexC6_OTA.cpp]
2026-07-04 Clamp engagement scaling, fix the speed-disengage gate and validate tune axes
    Extract four pure, host-testable helpers and rewire the inline call sites to
    them, then pin the corrected behaviour with three native test suites.
    - scale_haldex_engagement: the CAN parser scaled the raw engagement byte with
    Arduino map(), which extrapolates outside its window. An under-window byte
    produced a negative percent that wrapped when stored in the uint8_t engagement
    global; an over-window byte exceeded 100. It now clamps into the window first,
    so every generation stays 0-100 and in-window frames are byte-identical.
    - speed_disengage_ok: the passive-mode speed gate was
    (under==0) || (speed<=unde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
    [OpenHaldexC6_Calculations.cpp, OpenHaldexC6_can.cpp]
2026-07-04 feat: Verify and reconcile the low-power sleep feature
    Completed slices:
    - S01: Extract the wake decision into a host-tested pure seam
    - S02: Reconcile the README and CHANGELOG with the shipped feature
    Completed tasks:
    - S01/T01: Extracted the low-power wake decision into a pure lpCanActive() header seam and wired updateTriggers() to call it
    - S01/T02: Pinned the lpCanActive wake-decision seam with a 5-case native Unity characterization test (standalone fixed-50 and OEM threshold boundaries) that runs under `pio test -e native`.
    - S02/T01: Rewrote the README low-power section to describe the shipped, enabled-by-default feature with honest bench-pending and unverified-estimate callouts
    - S02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
    [OpenHaldexC6_IO.cpp]
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2026-07-05 test: prove the lock disengage-gate chatter and add a hysteretic fix seam
    The speed-disengage gate (speed_disengage_ok) is a bare comparison with no
    memory. getLockData re-evaluates it every chassis frame, so a speed signal
    resting on disengageUnderSpeed or disengageAboveSpeed and dithering by one unit
    flips the gate frame-to-frame and the lock target hunts 0 <-> target. The lock
    rate ramp masks the visible amplitude but cannot remove it, and with the ramp
    off (the default) the raw target reaches the wire unfiltered.
    test_lockgate makes the mechanism concrete (adjacent speeds either side of a
    bound give opposite answers) and pins disengage_gate_hysteresis, a Schmitt
    trigger: sharp entry, ex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
    [OpenHaldexC6_Calculations.cpp]
2026-07-05 test: prove force-mode flag chatter and add a debounce fix seam
    The TC/ESP, hazard, and external-button force-mode flags are read with a
    bare bitRead every chassis frame with no memory, so a single-frame edge
    flips force mode for one cycle and (with the release ramp off, the default)
    snaps the lock target unfiltered.
    Add debounce_force_flag() alongside the disengage-gate hysteresis seam from
    the previous commit: an integrating debounce that requires a raw edge to
    persist for N consecutive frames before accepting it, symmetric on engage
    and release, with any agreeing frame resetting the counter so a blip must be
    sustained. threshold <= 1 reduces exactly to today undebounced bitRead, so
    wirin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
    [OpenHaldexC6_Calculations.cpp]
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2026-07-05 feat: retune lock response sliders in milliseconds instead of percent-per-second
    The attack and release sliders were percent-per-second, which made time-based
    tuning painful: a "5 second decay" read as an obscure 5 %/s, and near the fast
    end a 10 ms change needed thousands of %/s of resolution, so you could not nudge
    it cleanly. They are now milliseconds for a full 0-100% travel: range 0-1000 ms
    in clean 10 ms steps, with 0 = instant in each direction.
    Making release instant at 0 also removes a footgun. Under the old unit a release
    rate of 0 meant "never releases" (clutch stuck locked), which is why release was
    floored at a nonzero rate; in milliseconds 0 cleanly means "snap open," so both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
    [OpenHaldexC6_Calculations.cpp, OpenHaldexC6_EEP.cpp, OpenHaldexC6_defs.h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]
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2026-07-09 refactor: slim the OTA module down to the provisioned-credential flow
    Trim the OTA implementation to the runtime-provisioned password path (no compiled-in credential), removing the dead legacy code so the flashing surface is the single fail-closed flow documented in the changelog.
    [OpenHaldexC6_OTA.cpp]
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2026-07-09 feat: Gen5 BPK full-lock torque ceiling as a setting, plus learn and fallback fixes
    The Fix Hunting (BPK) Motor_11 packing mapped 100% lock to a hardcoded 220 Nm of spoofed engine torque, so a 554K that never reached full engagement had no way to ask for more. It is now an adjustable full-lock torque ceiling on the Settings page (100-500 Nm, MQB signal max 509 Nm, default 220 so behaviour is unchanged until moved).
    The packing math was uint8 throughout, silently capping torque at 255 Nm; widened to the full signal range so a raised ceiling actually reaches the wire. The standalone and CAN-passthrough copies of the Motor_11 packing are de-duplicated into one host-tested bpk_pack_motor11 so t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
    [OpenHaldexC6_Calculations.cpp, OpenHaldexC6_StandaloneCAN.cpp, OpenHaldexC6_defs.h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]
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2026-07-10 Fix map-slot phantom, harden dashboard touch input, hold drive-mode pick
    Four field-reported bugs:
    - Saved map slot showed its name in the list but Load said "Empty slot".
    The list and Load endpoints tested occupancy differently: the list
    accepted any slot with a name and a blob key, while Load required the
    blob to be exactly the current struct size. A slot written by an older
    firmware layout therefore listed but wouldn't load. mapSlotNames now
    size-checks the blob to match mapSlotLoad, so a stale slot reads as
    empty and a fresh Save reclaims it.
    - Accidental toggle/slider changes while scrolling on the phone. Sliders
    get touch-action: pan-y so a vertical scroll passes throug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
    [OpenHaldexC6_EEP.cpp]
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2026-07-10 Fix map slots reading empty and add a slot picker for saving
    The saved-tune list and the Load action decided whether a slot was used with
    two different NVS calls - the list checked the blob's reported length via
    getBytesLength(), Load actually read the blob back with getBytes(). Those two
    can disagree (getBytesLength returns 0 for entries it doesn't classify as a
    plain blob), so a slot that loads fine could still be listed as empty. The list
    now reads the blob the same way Load does, so the two can never disagree.
    Empty slots were also disabled in the dropdown, so there was no way to choose
    which slot to save into - Save As just took the first free one. Empty slots are
    now selectable and ea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
    [OpenHaldexC6_EEP.cpp]
2026-07-10 Add per-corner slip and drive-mode over the diagnostic channel
    OpenHaldex now answers three supplier-specific UDS DIDs on the Haldex
    physical address (0x70F request, 0x779 response), the same channel that
    already carries clutch temps and PWM. The car's gateway does not forward
    the passive 0x6B0/0x6A0 broadcasts to the OBD port, so a tester on that
    port (the Rokketek gauge) could not otherwise read lock or set the mode.
    - 0xFDA0 (lock, read): commanded lock %, applied engagement, and the live
    drive mode, so a mode write can be confirmed by reading this back.
    - 0xFDA1 (slip, read): geometry-compensated per-corner slip, [FL,FR,RL,RR],
    signed int8 %/LSB. Each wheel's actual speed vs the spe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
    [OpenHaldexC6_Calculations.cpp, OpenHaldexC6_can.cpp, OpenHaldexC6_defs.h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]
2026-07-10 Restore slip no-data sentinel and reject zero-track geometry
    CodeRabbit review of PR #20:
    - The slip DID responder ignored compute_corner_slip's return, so its
    entry-time zeroing of slip_out overwrote the -128 no-data sentinel with
    false zeros on the too-slow/degenerate path. Honor the boolean and
    restore the sentinel, matching the dashboard path in the API.
    - Treat zero front/rear track as degenerate (it collapses the left/right
    corners onto the centreline), matching the documented contract, and
    cover both with tests.
    [OpenHaldexC6_Calculations.cpp, OpenHaldexC6_can.cpp]
2026-07-12 Stop showing the impossible Haldex fin temp and expose raw bytes to fix the decode
    The 0x2BE4 (fin) and 0x2BF1 (clutch) temperature scale, (raw - 22767)/100,
    was disassembled out of the upstream binary and never checked against a known
    temperature. Under sustained full pump duty the fin reads ~160C while clutch
    and module stay at ~30C. A 160C cooling fin is not physically possible, so the
    formula is wrong, not the reading.
    The correct scale cannot be recovered from the displayed numbers (linear decode
    has two unknowns; idle=30 is only one equation). So instead of guessing:
    - Expose the raw unscaled 16-bit wire value for both temp DIDs as
    coolingFinTempRaw / clutchTempRaw in the /api JSON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
    [OpenHaldexC6_Calculations.cpp, OpenHaldexC6_UDS.cpp, OpenHaldexC6_defs.h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]
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2026-07-12 Drive BPK whenever a valid learn table exists, not just with Fix Hunting on
    A Learn always runs under BPK packing, so the table it builds is calibrated
    against BPK frames. Driving with Fix Hunting off previously sent the V3 frame
    while still applying that BPK-measured table - the calibration was matched to a
    frame that mode never sends, so lock behaved differently than during the Learn.
    motor11_use_bpk_packing now returns fixHunting || learnActive || learnTableValid.
    Once a valid table exists the frame path stays BPK on drive regardless of the
    switch, so what you calibrate is what you drive. Untuned users (no table) keep
    the legacy V3 default. The standalone CAN path now routes through the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
    [OpenHaldexC6_Calculations.cpp, OpenHaldexC6_StandaloneCAN.cpp, test_learn.cpp]
2026-07-12 Address CodeRabbit review: null UDS temps until valid, a11y + doc fixes
    - Publish UDS clutch/cooling-fin temps (decoded and raw) as null until the
    DID has decoded at least once this session, cleared on session teardown.
    Before this a capture client could not tell the reset 0 from a real 0 degC
    reading, which corrupts the raw-byte capture used to solve the temp scale.
    - Give the lock-calibration slider an accessible name via aria-labelledby.
    - Correct the standalone Motor_11 header comment: packing is BPK when Fix
    Hunting is on, a learn is active, or a valid learn table exists - not
    strictly the user toggle.
    - Reword 'a Learn' as a noun to 'a learning run' in the changelog.
    - Align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
    [OpenHaldexC6_StandaloneCAN.cpp, OpenHaldexC6_UDS.cpp, OpenHaldexC6_defs.h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]
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2026-07-13 Add Software Update card and web-UI (LittleFS) OTA
    The OTA endpoints existed but nothing in the UI linked to them, and only
    firmware could be updated over the air - the web UI itself always needed
    a USB cable.
    Firmware: new POST /ota/updatefs writes an uploaded LittleFS image
    straight to the filesystem partition (unmount, rolling sector erase,
    esp_partition_write, reboot). Same safe-state gate as firmware OTA on
    chunk 0, plus a 0xE9 magic-byte guard so a firmware image aimed at the
    filesystem slot is rejected instead of silently blanking the UI.
    Web UI: Software Update card on the Settings tab shows version, build,
    running slot and the live safe-state reason from /ota/info + /ota/check,
    an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
    [OpenHaldexC6_OTA.cpp]
2026-07-13 Single-file OTA: /ota/update now takes the merged image and splits it
    The Settings-page update card is now one upload slot. It accepts the
    release's firmware-merged.bin (the same file used for USB flashing) and
    updates firmware and web UI in one go: the handler classifies the upload
    from its first bytes and routes each chunk of a merged image by flash
    offset - app segment to the spare OTA slot, filesystem segment to the
    LittleFS partition, bootloader/partition-table/NVS regions skipped so
    settings and the learn table survive. Bare firmware.bin and littlefs.bin
    still work, and /ota/updatefs stays as the explicit filesystem endpoint.
    Wrong-file guards now check real image magics: filesystem w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
    [OpenHaldexC6_OTA.cpp]
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
